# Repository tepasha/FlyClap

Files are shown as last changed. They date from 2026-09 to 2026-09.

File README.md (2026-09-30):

# 🪰 fly-defense

Модульні DIY-пристрої на Arduino та ESP32 для боротьби з мухами. Спершу збирається **основа** (плата, живлення, тумблер ARM, статус-LED), до неї роз'ємами JST-XH підключаються **модулі** на вибір: ІЧ-завіса, хлопавка, турель, сонар, камера. Три готові пристрої — типові комбінації модулів, див. [docs/modules.md](docs/modules.md).

| Проєкт | Принцип | Сенсор | Виконавчий механізм | Реакція |
|---|---|---|---|---|
| [**FlyClap**](docs/flyclap.md) | «Хлопавка»: муха пролітає між пластинами → вони схлопуються | ІЧ-завіса (4 промені) + LM339 | Соленоїд-засувка + пружини, серво взводить | ~25 мс |
| [**FlySonar — Arduino**](docs/flysonar.md) | Турель: ехолокатор сканує зону, водомет стріляє по цілі | HC-SR04 на pan-tilt | Помпа або клапан + сопло, 2 серви | ~3 с скан + ~1–2 с уточнення |
| [**FlySonar — ESP32**](docs/flysonar-esp32.md) | Та сама турель на одній ESP32-CAM: камера над підсвіченим фоном, бачить і мошку | ESP32-CAM + LED-панель | Клапан + розпилювач, 2 серви | ~70–90 мс |

## Структура

```
fly-defense/
├── platformio.ini              # проєкт PlatformIO (фреймворк Arduino): плати й середовища
├── lib/FlyDefense/             # бібліотека: основа (Base) і модулі
│   └── src/fly/                #   IrCurtain, ClapLatch, Turret, PanTilt, Nozzle, Sonar,
│                               #   CameraEyes, EyesLink, LinkOut
├── src/                        # прошивки = готові збірки модулів (по одній на середовище)
│   ├── flyclap/                # ІЧ-завіса + хлопавка
│   ├── flysonar/               # турель із сонаром (Arduino)
│   ├── flysonar_turret/        # турель на Arduino, цілі від ESP32 "очей"
│   ├── flysonar_eyes/          # ESP32-CAM як "очі" для Arduino
│   ├── flysonar_esp32/         # турель на одній ESP32-CAM
│   └── mybuild/                # шаблон своєї збірки
├── test/                       # тести модулів на ПК (pio test -e native), макет Arduino API
├── docs/
│   ├── modules.md              # основа + модулі, роз'єми JST-XH, свій модуль
│   ├── flyclap.md              # механіка, BOM, схема, налаштування
│   ├── flysonar.md             # Arduino-версія
│   ├── flysonar-esp32.md       # ESP32-версія: фон, підключення, калібрування
│   └── shopping-list.md        # зведений список покупок для обох проєктів
├── schematics/                 # схеми підключення, роз'єми JST-XH, ілюстрації (SVG + PNG)
├── cad/flyclap/                # корпус FlyClap для 3D-друку: STEP (FreeCAD), STL, модель CadQuery
├── cad/flysonar/               # турель FlySonar (обидві версії) і коробка основи для 3D-друку
├── tools/diagrams.py           # генератор схем
└── LICENSE
```

Що купити — див. [docs/shopping-list.md](docs/shopping-list.md). Для 3D-друку: корпус FlyClap — [cad/flyclap](cad/flyclap/README.md), турель FlySonar — [cad/flysonar](cad/flysonar/README.md).

## Як виглядають пристрої

| FlyClap | FlySonar — Arduino | FlySonar — ESP32 |
|---|---|---|
| FlyClap | FlySonar Arduino | FlySonar ESP32 |
| [схема підключення](schematics/flyclap-wiring.svg) · [варіант TSSP4038](schematics/flyclap-tssp.svg) | [схема підключення](schematics/flysonar-arduino-wiring.svg) | [схема підключення](schematics/flysonar-esp32-wiring.svg) |

Роз'єми основи й модулів — на окремій схемі: [modules-connectors](schematics/modules-connectors.svg).

Усі картинки — у папці [`schematics/`](schematics/) (SVG і PNG для друку/телефона). Їх генерує `tools/diagrams.py`: правите скрипт → `python3 tools/diagrams.py --png`.

## Збірка

Проєкт зроблено під [PlatformIO](https://platformio.org/) з фреймворком Arduino. Відкрийте теку репозиторію у VS Code з розширенням PlatformIO IDE або користуйтесь командним рядком; плати, тулчейни й бібліотеку `Servo` PlatformIO завантажить сам.

```bash
pio run -e flyclap -t upload
pio run -e flysonar -t upload
pio device monitor -b 115200
```

> Клони Uno на CH340 потребують драйвера CH340 (Windows/macOS), якщо плату не видно як COM/tty-порт.
>
> Прошивки використовують лише ресурси ATmega328P і працюють без змін і на Nano. Для нього є окремі середовища: `pio run -e flyclap_nano -t upload`, `pio run -e flysonar_nano -t upload`.

FlySonar, ESP32-версія: `pio run -e flysonar_esp32 -t upload` (ESP32-CAM) або `flysonar_esp32_s3` (ESP32-S3 CAM) — див. [docs/flysonar-esp32.md](docs/flysonar-esp32.md).

Інші варіанти: `flyclap_tssp` (завіса TSSP4038), `flysonar_turret` (+ `_nano`) разом з `flysonar_esp32_eyes` (ESP32 як «очі» для Arduino), `mybuild` (шаблон своєї збірки). Кожне середовище збирає одну прошивку з `src/`; модулі лежать у `lib/FlyDefense`.

### Тести
```bash
pio test -e native   # на ПК; потрібен g++ у PATH
```
Модулі бібліотеки на макеті Arduino API: основа (ARM, LED, конфлікти пінів), хлопавка, турель, збірка «турель + очі», симуляція сонара (віртуальна кімната + модель пелюстки HC-SR04), зір на синтетичних кадрах.

## Безпека

- **FlyClap**: механізм у корпусі з сіткою ~8 мм, пальці не пролазять. Соленоїд живиться лише короткими імпульсами.
- **FlySonar**: фільтр великих об'єктів не стріляє по руках і тваринах, а режим SAFE (тумблер ARM вимкнено) тільки логує цілі. Електроніку тримайте вище за рівень води й за перегородкою.
- Жодних лазерів і високої напруги: свідоме архітектурне рішення, пояснене в [docs/flyclap.md](docs/flyclap.md).

## Ліцензія

MIT, див. [LICENSE](LICENSE).

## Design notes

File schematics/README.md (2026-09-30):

# 📐 Схеми та ілюстрації

Схеми підключення й картинки «як виглядає пристрій» для всіх пристроїв. Кожна картинка є у двох форматах:

- **SVG** (у цій папці): масштабується без втрат, показується в документації на GitHub;
- **PNG** (у [`png/`](png/)): 2400 px завширшки, щоб відкрити на телефоні або роздрукувати.

| Пристрій | Як виглядає | Схема підключення |
|---|---|---|
| **FlyClap** | [SVG](flyclap-device.svg) · [PNG](png/flyclap-device.png) | варіант A (LM339): [SVG](flyclap-wiring.svg) · [PNG](png/flyclap-wiring.png)<br>варіант B (TSSP4038): [SVG](flyclap-tssp.svg) · [PNG](png/flyclap-tssp.png) |
| **FlySonar — Arduino** | [SVG](flysonar-arduino-device.svg) · [PNG](png/flysonar-arduino-device.png) | [SVG](flysonar-arduino-wiring.svg) · [PNG](png/flysonar-arduino-wiring.png) |
| **FlySonar — ESP32** | [SVG](flysonar-esp32-device.svg) · [PNG](png/flysonar-esp32-device.png) | [SVG](flysonar-esp32-wiring.svg) · [PNG](png/flysonar-esp32-wiring.png) |

| **Основа і модулі** | — | роз'єми JST-XH, розпіновка, що до якого піна: [SVG](modules-connectors.svg) · [PNG](png/modules-connectors.png) |

Кольори дротів на всіх схемах однакові: 🔴 +12 В · 🟠 +5 В · 🟣 живлення серв · 🔵 сигнали · ⚫ земля.

Зелені мітки біля сигналів — роз'єм основи й контакт: `B·3` означає роз'єм B, контакт 3. Типи роз'ємів описані в [docs/modules.md](../docs/modules.md#залізо-розєми-jst-xh).

Ілюстрації умовні (пропорції не в масштабі), це не креслення для кріплень. Подробиці — у документації: [FlyClap](../docs/flyclap.md), [FlySonar — Arduino](../docs/flysonar.md), [FlySonar — ESP32](../docs/flysonar-esp32.md).

## Як оновити

Картинки генерує [`tools/diagrams.py`](../tools/diagrams.py) (лише стандартна бібліотека Python). Змінили пін чи номінал — правите скрипт і з кореня репозиторію запускаєте:

```bash
python3 tools/diagrams.py          # лише SVG
python3 tools/diagrams.py --png    # SVG + PNG (потрібен Chromium; шлях можна задати змінною CHROME)
```

---

FlyClap — як виглядає
FlyClap — схема, варіант A
FlyClap — схема, варіант B
FlySonar Arduino — як виглядає
FlySonar Arduino — схема
FlySonar ESP32 — як виглядає
FlySonar ESP32 — схема
Основа і модулі — роз'єми JST-XH

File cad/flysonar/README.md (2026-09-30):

# FlySonar — турель pan-tilt для 3D-друку

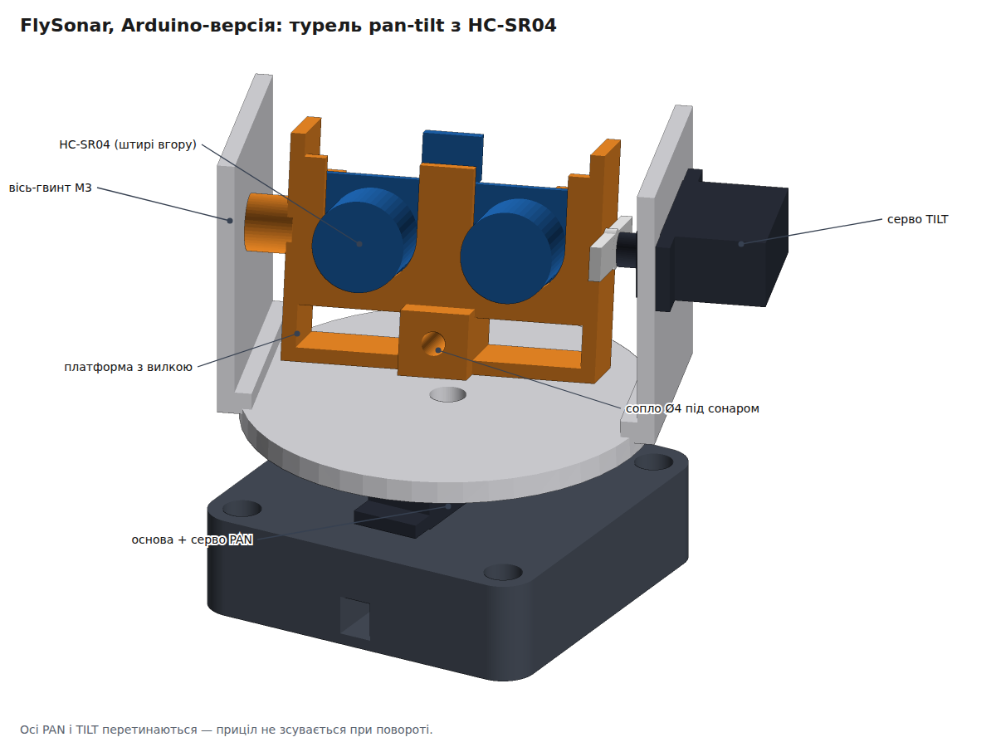
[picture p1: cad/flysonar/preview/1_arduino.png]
Arduino-версія


Одна поворотна основа під **дві версії** FlySonar:

| | Головка | Що ще друкувати |
|---|---|---|
| **Arduino-версія** ([docs/flysonar.md](../../docs/flysonar.md)) | `head_sonar`: HC-SR04 + сопло Ø4 під ним | — |
| **ESP32-версія** ([docs/flysonar-esp32.md](../../docs/flysonar-esp32.md)) | `head_nozzle`: лише сопло, точно на осі нахилу | `camera_post` + `camera_cradle` (кріплення ESP32-CAM) |

Під мікросерво **MG90S / SG90 / ES08MD**. Осі PAN і TILT перетинаються в одній точці, тож приціл не зсувається при повороті. Габарит турелі разом із серво TILT — близько 95 × 80 мм, висота до осі нахилу 65 мм.

| ESP32-версія | Нахил (розріз по центру) |
|---|---|
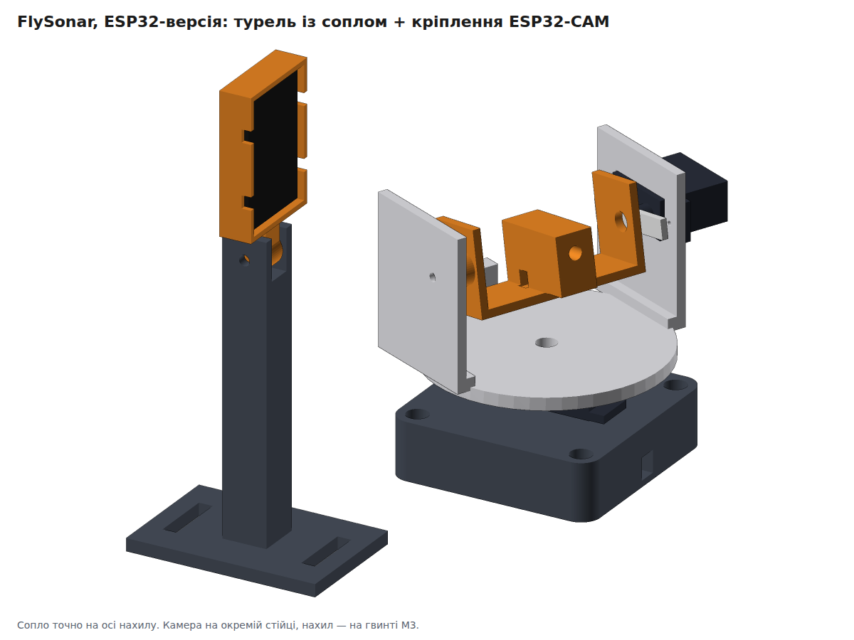
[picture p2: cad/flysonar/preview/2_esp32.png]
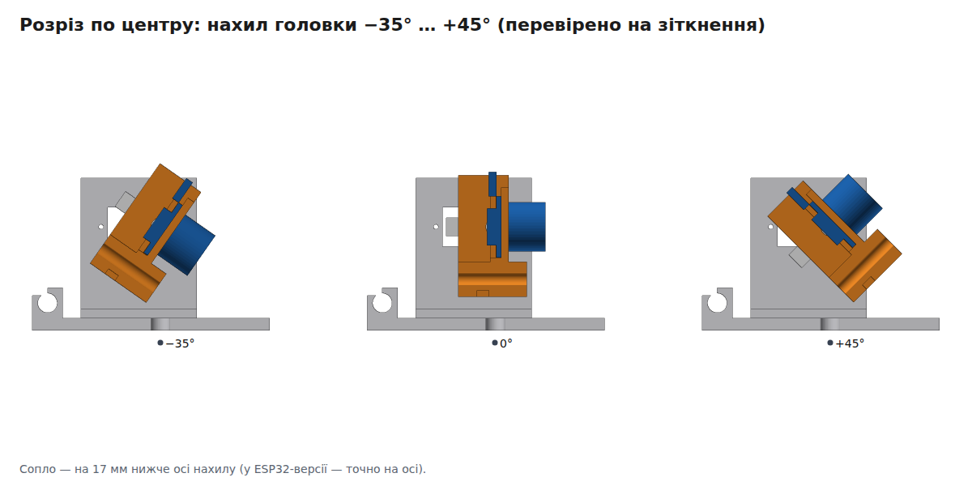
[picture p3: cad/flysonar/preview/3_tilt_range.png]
|  |  |

## Файли

| Що | Для чого |
|---|---|
| [`step/`](step/) | кожна деталь у STEP. **Відкривається у FreeCAD** (File → Open) |
| [`turret_arduino_assembly.step`](turret_arduino_assembly.step), [`turret_esp32_assembly.step`](turret_esp32_assembly.step) | складання з кольорами й назвами (разом із муляжами серв і HC-SR04) |
| [`stl/`](stl/) | для слайсера |
| [`flysonar_turret.py`](flysonar_turret.py) | параметрична модель (CadQuery) з перевірками |

Щоб отримати документ FreeCAD: відкрийте складання й зробіть **File → Save As → `.FCStd`**.

## Деталі для друку

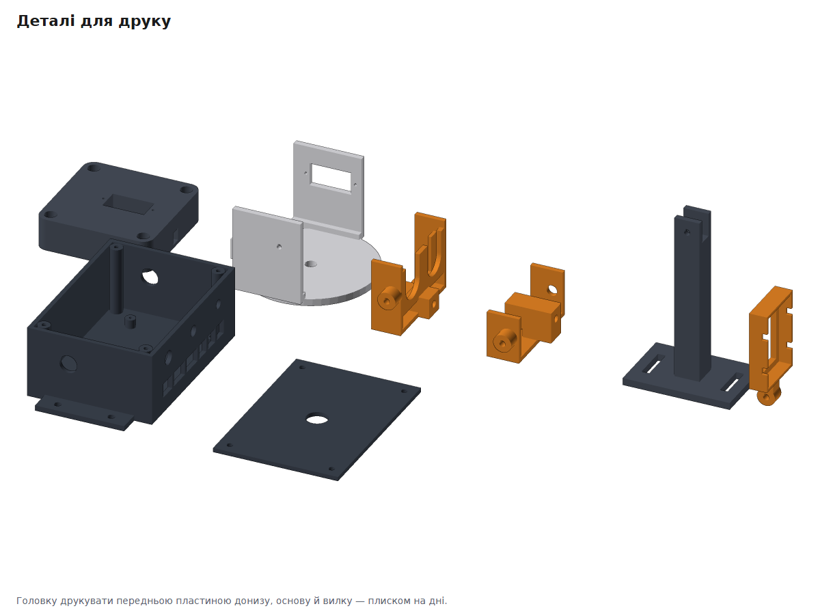
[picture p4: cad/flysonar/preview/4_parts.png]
Деталі


| Деталь | Орієнтація на столі | Примітка |
|---|---|---|
| `base` | плиском на дні | кишеня під серво PAN, проріз для кабелю, 4 отвори для кріплення до дошки |
| `yoke` | платформою донизу | платформа + вилка; права стійка з вікном під серво TILT, ззаду затискач шланга |
| `head_sonar` | передньою пластиною донизу | U-пази під випромінювачі HC-SR04, блок сопла |
| `head_nozzle` | плиском на дні | для ESP32-версії |
| `camera_post` | плиском на основі | стійка ESP32-CAM, висота осі 90 мм |
| `camera_cradle` | лицьовою рамкою донизу | рамка під плату 27 × 40,5 з великим вікном під лінзу |
| `electronics_box`, `electronics_lid` | коробка стоячи на дні, кришка плиском | коробка основи: плата 5 × 7 см, вікна під роз'єми JST-XH, лапки під шурупи |

PETG або PLA, шар 0,2 мм, 3 периметри, 20–30 %. Підтримки не потрібні.

## Кріплення та інше

| Що | К-сть | Для чого |
|---|---|---|
| Мікросерво MG90S (або цифрові ES08MD II) | 2 | PAN і TILT |
| Саморізи 2 мм з комплекту серв | 8 | вушка серв (по 4) |
| Саморізи з комплекту серв | 2 + 4 | центральні гвинти качалок + качалки до платформи й головки |
| Гвинт М3 × 12 | 1 | вісь нахилу з лівого боку: вкручується в стійку (отвір 2,8), головка обертається на ньому |
| Гвинти М3 / шурупи 3,5 мм | 4 | основа до дошки |
| Гвинт М3 × 16 + гайка | 1 | вісь нахилу камери (ESP32-версія) |
| Гвинти М4 | 2 | стійка камери до дошки |
| Латунна трубка / голка Ø4 | 1 | сопло |
| Стяжки 3 мм | 3 | сопло, плата ESP32-CAM |

## Складання

1. **Спершу виставте обидві серви на 90°** (прошивкою або тестером), і лише потім надягайте качалки. Тоді 90° означає «прямо вперед» і «горизонтально», як очікує прошивка.
2. **Серво PAN** вставте в основу (кабель у проріз, вушка лягають на верх), прикрутіть саморізами.
3. **Качалка PAN → платформа.** Покладіть качалку на низ платформи по центру, позначте отвори, просвердліть ∅1,5 і прикрутіть. Надягніть платформу на вал так, щоб вилка дивилась уперед (+X), і закрутіть центральний гвинт через отвір у платформі.
4. **Серво TILT** вставте у вікно правої стійки ззовні (вал усередину, корпус назад) і прикрутіть вушка.
5. **Головка.**
   - `head_sonar`: HC-SR04 **штирями вгору** опустіть згори в паз, щоб випромінювачі лягли в U-пази передньої пластини. Сопло вставте в отвір під сонаром і притягніть стяжкою.
   - `head_nozzle`: сопло в центральний отвір, стяжка.
6. **Качалка TILT → права щока головки.** Центр качалки над отвором ∅6, отвори просвердлити по місцю. Надягніть головку качалкою на вал серви (горизонтально), закрутіть центральний гвинт через отвір ∅6. Зліва вкрутіть М3 × 12 крізь стійку у втулку головки: головка обертається на гвинті.
7. **Шланг** з петлею-запасом проведіть через затискач ззаду платформи.
8. **ESP32-CAM:** плату вкладіть у рамку ззаду камерою до вікна, притягніть двома стяжками. Рамку вставте язичком у вилку стійки на М3 × 16: гайка дає фіксацію нахилу.

## Коробка основи й роз'єми модулів

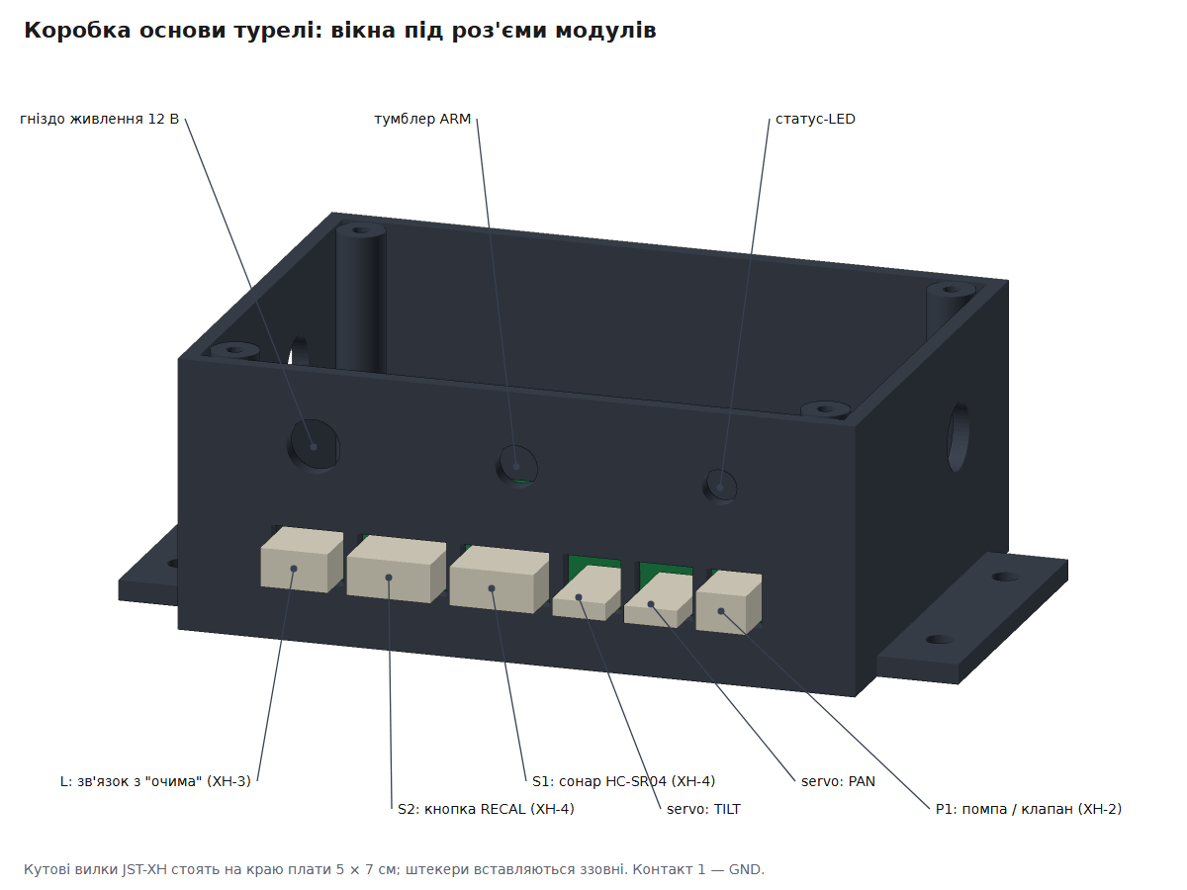
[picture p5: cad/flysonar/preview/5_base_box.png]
Коробка основи


`electronics_box` — це **основа** модульної системи ([docs/modules.md](../../docs/modules.md)): у ній контролер, DC-DC, силовий ключ, тумблер ARM і статус-LED, а модулі турелі підключаються роз'ємами. Коробка кріпиться до дошки чотирма шурупами через лапки. Плата 5 × 7 см стоїть на чотирьох стійках, зсунута до стінки з вікнами: між краєм плати й стінкою 0,6 мм. **Кутові вилки JST-XH (S2B/S3B/S4B/S6B-XH-A) і кутову гребінку серви припаюйте на самому краю плати, навпроти свого вікна**; тоді штекер модуля вставляється ззовні крізь стінку. Над вікнами — отвори під гніздо живлення ∅8, тумблер ARM ∅6,3 і статус-LED ∅5,2; у торцях — отвори ∅10 під силові дроти.

| Вікно | Роз'єм | Модуль | Версії |
|---|---|---|---|
| L | XH-3 | зв'язок з «очима» ESP32 | Arduino + «очі» |
| S2 | XH-4 | кнопка RECAL | Arduino (сонар) |
| S1 | XH-4 | сонар HC-SR04 | Arduino (сонар) |
| servo ×2 | 3-pin 2,54 | серви TILT і PAN | усі |
| P1 | XH-2 | помпа або клапан | усі |

В ESP32-версії контролер — сама ESP32-CAM на стійці камери; у коробці тоді лишаються DC-DC, ключ AO3400, тумблер ARM і роз'єми серв та клапана. Набір вікон задає список `BASE_PORTS` на початку скрипта; коробку будує `base_box()` у [`cad/cadlib.py`](../cadlib.py), спільна з корпусом FlyClap.

## Що перевіряє скрипт

`python3 cad/flysonar/flysonar_turret.py` (потрібно `pip install cadquery`):
- кожна деталь влазить на стіл 220 × 220 × 250 мм і є одним цілим тілом;
- **жодних зіткнень** на всьому діапазоні руху: нахил −35…+45°, поворот −90…+90° (прошивка використовує ±60°), для обох головок. Перевіряються вилка, серви, качалки, головка, HC-SR04 і основа;
- **HC-SR04 справді вставляється** згори в головку (плата ковзає 40 мм і ніде не чіпляє). Ця перевірка з'явилася після того, як перша версія з круглими отворами виявилася нескладальною;
- рамка камери нахиляється на ±25° і не зачіпає стійку;
- плата стає на стійки коробки основи, **кожен штекер проходить у своє вікно**, а сама коробка не заважає турелі й стійці камери.

Прапорці: `--no-export` (лише перевірки), `--preview` (картинки; numpy і Chromium, шлях можна задати в `CHROME`).

## Змінити розміри

Параметри на початку скрипта: розміри серви (`SV_*`), HC-SR04 (`SR_*`), діаметр сопла `NOZ_D` (6,2 для силіконової трубки 4 × 6), висота осі нахилу, висота стійки камери, зазор `CLR`. Після змін запустіть скрипт: перевірки покажуть, чи нічого не зачіпається.

## Обмеження (чесно)

- **Розміри серв і HC-SR04** взято з типових креслень, а клони відрізняються до 1 мм. **Звірте штангенциркулем** і за потреби виправте `SV_*` / `SR_*`. Найважливіші — відстань від торця корпусу до вала `SV_SHAFT_OFF` і висота вушок `SV_TAB_Z`.
- **Вікна під роз'єми** розраховано за розмірами колодок JST-XH з даташита (ширина 2,5 × (n − 1) + 4,9 мм) із зазором 0,8 мм. Розташування вилок на платі залежить від вашого монтажу: приміряйте плату в коробці до пайки.
- **Отвори під гвинти качалок** не змодельовані, бо форма качалок різна. Їх свердлять по місцю (крок 3 і 6).
- **Не надруковано й не перевірено на залізі:** перевірки геометричні. Мікросерво тримає головку з HC-SR04 без проблем, але шланг має бути м'який, з петлею, щоб не тягнув турель.
- **Паралакс сопла.** У Arduino-версії сопло на 17 мм нижче сонара, і прошивка це враховує (`TILT_NOZZLE_OFFSET10`). Після складання уточніть поправки пробними пострілами, як описано в [docs/flysonar.md](../../docs/flysonar.md).

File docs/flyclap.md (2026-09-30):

# FlyClap — збивач мух на льоту на Arduino

## Чому саме така архітектура

| Ідея | Чому ні |
|---|---|
| Камера + наведення | ATmega328 не потягне комп'ютерний зір; муха летить 1–3 м/с, pan-tilt просто не встигне |
| Лазер | Небезпечно для очей людей і тварин, не варто навіть як експеримент |
| Електросітка | Потрібна висока напруга — не для DIY-плати на столі |

**Рішення:** не наводимося на муху, а робимо зону, де вона гарантовано пролетить (приманка), і перекриваємо її всю одним швидким механізмом. Arduino тут робить те, що вміє найкраще — реагує за мікросекунди.

Бюджет часу: переривання ~5 мкс → засувка ~5 мс → пластини схлопуються ~15–20 мс. За ~25 мс муха пролітає 3–6 см, тому пластини 15×15 см з ІЧ-завісою по центру її накривають.

## Механіка

FlyClap — як виглядає пристрій

> **Корпус для 3D-друку** (STEP для FreeCAD, STL, інструкція зі складання): [cad/flyclap](../cad/flyclap/README.md).

- Дві легкі пластини (оргскло 2 мм або PET), на петлях, стягуються пружинами/гумками.
- Засувка тримає їх розведеними, соленоїд її вибиває.
- Сервопривід розводить пластини назад до зачеплення засувки, кінцевик підтверджує "взведено", важіль відходить.
- Корпус закритий сіткою з вічком ~8 мм — механізм не може прищемити пальці.

## Компоненти (BOM)

### Контролер і живлення
| Деталь | К-сть | Примітка |
|---|---|---|
| Arduino **Nano** (ATmega328P, CH340) | 1 | Рекомендовано: дешевше й компактніше за Uno + Proto Shield. Uno R3 теж підходить |
| Макетна плата 5×7 см (для Nano) або Proto Shield (для Uno) | 1 | Компаратор, MOSFET і роз'єми розпаюються на ній |
| БЖ 12 В 2 А + гніздо DC 5.5×2.1 | 1 | |
| DC-DC понижувач на 5–6 В, ≥3 А (XL4015 / LM2596) | 1 | Тільки для серви |
| Електроліт 470–1000 мкФ 16 В | 1 | Біля серви |
| Електроліт 1000–2200 мкФ 25 В | 1 | Біля соленоїда, див. «Швидкий соленоїд» |
| Кераміка 100 нФ | 5 | Біля LM339, Arduino, DC-DC |

### ІЧ-завіса (базовий варіант, `IrCurtain::COMPARATOR`)
| Деталь | К-сть | Примітка |
|---|---|---|
| ІЧ-світлодіод 940 нм (напр. TSAL6200) | 4 (+2 запас) | |
| Резистор 150 Ом | 4 | Струм світлодіодів ~25 мА від 5 В |
| Фототранзистор з ІЧ-фільтром (TEFT4300) | 4 (+2) | |
| Резистор 10 кОм | 8 | 4× підтяжка фототранзисторів, 4× підтяжка виходів LM339 (відкритий колектор, без них не працює) |
| **Резистор 1 МОм** | 4 | Гістерезис компаратора, див. нижче |
| LM339 + панелька DIP-14 | 1 | |
| Підстроювальний резистор 10 кОм (багатообертовий 3296) | 4 | Дільник 5 В ↔ GND, повзунок → вхід «−» |

### Виконавчі механізми та керування
| Деталь | К-сть | Примітка |
|---|---|---|
| Соленоїд 12 В push/pull, хід ~5 мм (типу JF-0530B) | 1 | |
| IRLZ44N | 1 | + 100 Ом у затвор, 10 кОм затвор→GND |
| Діод 1N5819 | 1 | Паралельно котушці |
| Сервопривід MG996R | 1 | Живлення від DC-DC, **не** від піна 5V |
| Мікроперемикач (кінцевик) з важелем | 1 | |
| **Пасивний** п'єзо-бузер | 1 | `tone()` потребує пасивного; у TSSP-варіанті — активний |
| Тумблер ARM, світлодіод + 330 Ом | 1 | |

### Механіка
- Оргскло 2 мм / PET — 2 пластини 15×15 см, 2–4 маленькі петлі, пружини розтягу або гумки
- Засувка (3D-друк або алюмінієвий кутик), корпус, сітка з вічком ~8 мм
- Чорна термоусадка на фототранзистори, дроти, клемники, приманка

**Живлення Uno:** 12 В від того ж БЖ можна подати в DC-джек або на Vin, вбудований стабілізатор Uno це приймає. Але 5V-пін Uno дає лише ~500 мА, і соленоїд та серва від нього **не** живляться.

## Схема підключення

FlyClap — схема підключення, варіант A

| Arduino | Куди |
|---|---|
| D4–D7 | виходи LM339 (підтяжка 10 кОм до 5 В). Промінь цілий = LOW, перекритий = HIGH |
| D8 | кінцевик на GND (LOW = взведено) |
| D9 | затвор IRLZ44N → соленоїд до +12 В |
| D10 | сигнал серви |
| D11 | бузер |
| D13 | статус-LED |
| A0 | тумблер ARM на GND |

Кожен канал завіси: фототранзистор + резистор 10 кОм → вхід "+" компаратора; підстроювальник → вхід "−". Колектор фототранзистора закрити трубкою (термоусадка) від зовнішнього світла.

**Гістерезис (обов'язково).** Резистор **1 МОм з виходу кожного компаратора на його вхід «+»**. Фототранзистор дає повільний фронт, і без гістерезису компаратор на порозі «дзвенить»: десятки перемикань, кожне з яких викликає переривання. Гістерезис ≈ 5 В × 10 кОм / 1 МОм ≈ 50 мВ. Якщо на межі все одно тремтить, поставте 470 кОм (~100 мВ).

**Швидкий соленоїд.** Електроліт 1000–2200 мкФ між +12 В і силовою землею якомога ближче до соленоїда. Він віддає пусковий струм, тому засувка вибивається швидше, а БЖ і Arduino не просідають у момент пострілу.

### Альтернатива: модульована завіса TSSP4038 (`IrCurtain::TSSP`, середовище `flyclap_tssp`)

Замість фототранзисторів, LM339 і підстроювальників ставляться 4 приймачі **TSSP4038**, які реагують лише на ІЧ, модульоване на 38 кГц. Завіса перестає боятися сонця й ламп, і налаштовувати нічого не треба. Прошивка генерує несучу апаратно (Timer2 → D3).

FlyClap — варіант B, TSSP4038

| Що | Підключення |
|---|---|
| TSSP4038 ×4 | OUT → D4–D7, VS → 5 В через 100 Ом + 100 нФ до GND (на кожен приймач) |
| ІЧ-світлодіоди ×4 | кожен через свій резистор 68 Ом від 5 В на колектор BC337 (або стік IRLZ44N) |
| D3 | 1 кОм → база BC337, емітер → GND |
| D11 | **активний** бузер (Timer2 зайнятий несучою, `tone()` недоступний) |

У цьому варіанті всі приймачі бачать усі світлодіоди, тому **трубки на світлодіодах і на приймачах обов'язкові**. Інакше перекритий промінь «підсвітять» сусіди. Якщо промінь не перекривається сірником, збільшуйте резистор світлодіодів (68 → 220 Ом → 1 кОм): на 15 см сигналу вистачає з великим запасом. Реакція приймача ~0.3–0.5 мс, у бюджеті 25 мс це непомітно.

Найпростіший варіант без компаратора: готові модулі ІЧ-завіси (break-beam) з виходом на відкритому колекторі підключаються прямо в D4–D7 у режимі `COMPARATOR` з підтяжками 10 кОм.
**Загальна земля обов'язкова**, силові земля соленоїда/серви — зіркою до БЖ, не через Uno.

## Налаштування

1. Прошити, відкрити Serial Monitor на 115200.
2. Тумблер ARM вимкнено. Для кожного каналу крутити підстроювальник, поки вихід стабільно LOW при чистому промені і HIGH, коли його перекриває сірник.
3. Підібрати `SERVO_COCK_DEG`, щоб засувка чітко клацала, і `SERVO_REST_DEG`, щоб важіль не заважав пластинам (константи в `lib/FlyDefense/src/fly/ClapLatch.h`).
4. Увімкнути ARM: пік → взвод → короткий пік = "ARMED".

## Індикація

| LED | Значення |
|---|---|
| коротке мигання раз на 2 с | SAFE: ARM вимкнено |
| горить | ARM, усе готово |
| повільно блимає | ARM, модуль зайнятий |
| швидко блимає | аварія, помилка конфігурації або немає зв'язку |

Та сама мова LED у всіх пристроях, див. [modules.md](modules.md#основа-flybase).

У FlyClap «зайнятий» — це взвод або очікування чистої завіси. Швидке блимання з довгим гудком — FAULT (застрягла засувка або щось лежить у промені). Скидання: вимкнути й увімкнути ARM.

## Прошивка — ключові рішення

Прошивка — `src/flyclap/main.cpp`: основа + модулі `IrCurtain` (тригер) і `ClapLatch` (виконавець) з бібліотеки `lib/FlyDefense`. Будь-який з них можна замінити, див. [modules.md](modules.md). Модулі підключаються до основи роз'ємами JST-XH (зелені мітки на схемі); вікна під них є в блоці електроніки корпусу.

- Соленоїд вмикається **прямо в ISR** (pin-change переривання завіси), не в `loop()` — економить до кількох мс.
- Повторне читання через 30 мкс у ISR відсіює ЕМ-завади від самого соленоїда та серви.
- Озброєння лише після 500 мс стабільно чистої завіси, щоб не стріляти по прилиплій мусі.
- Лічильник **спрацювань** (`claps`) зберігається в EEPROM. Це кількість схлопувань, а не підтверджених мух: пил чи комаха теж рахуються.
- Серво під'єднується (`attach`) лише на час руху. Коли важіль повернувся в спокій, воно відключається: не тремтить, не гуде, не тягне струм і не наводить завад на завісу. Важіль у спокої ніщо не навантажує, тож утримувати його не треба.
- Час пострілу, записаний в ISR (32 біти), `tick()` модуля читає в `ATOMIC_BLOCK`.

## Ідеї для v2

- Два шари завіси → оцінка швидкості та затримка спрацювання під траєкторію.
- OLED із лічильником, живлення від 18650.

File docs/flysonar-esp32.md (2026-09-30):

# FlySonar — ESP32-версія (камера, бачить мошку)

Одна плата **ESP32-CAM** або **ESP32-S3-CAM** робить усе: бачить комаху на підсвіченому фоні, веде ціль, наводить серви й відкриває клапан. **Arduino не потрібен.** Вона бачить **мошку 1–3 мм** і може стріляти по цілі в польоті.

Arduino-версія (сонар HC-SR04) описана в [flysonar.md](flysonar.md).

| | Arduino-версія | ESP32-версія |
|---|---|---|
| Плата | Arduino Uno / Nano | ESP32-CAM або ESP32-S3-CAM |
| Сенсор | HC-SR04 на турелі | камера над підсвіченим фоном |
| Кого бачить | мухи 6–8 мм, що сидять, 10–40 см | мухи й мошка 1–3 мм, у т.ч. в польоті |
| Точність | ~0,5° після уточнення | ~1 мм у площині фону (після калібрування) |
| Реакція | ~3 с скан + 1–2 с уточнення | ~70–90 мс |
| Прошивка | `src/flysonar` | `src/flysonar_esp32` |

FlySonar, ESP32-версія — як виглядає пристрій

> **Турель і кріплення камери для 3D-друку:** [cad/flysonar](../cad/flysonar/README.md) (головка `head_nozzle` + `camera_post` / `camera_cradle`).

## Чому саме так

- **Підсвічений фон.** Комаха на світлій панелі дає чорну тінь з величезним контрастом, без складного розпізнавання. Так працюють і промислові оптичні «паркани» для комарів. Світла панель ще й сама приваблює комах, і вони **сідають на неї**. Це найлегші цілі, і для них немає паралакса (див. нижче).
- **Роздільність.** QVGA 320×240 на полі шириною ~30 см дає ~1 мм на піксель, тобто мошка займає 2–4 пікселі. Алгоритм ловить плями від 2 пікселів.
- **Камера нерухома, окремо від турелі.** Калібрування «піксель → кути серв» робиться тестовими пострілами, тож зміщення сопла й провисання струменя входять у модель автоматично.
- **Два ядра.** Зір працює в `loop()`. Серви, клапан, тумблер ARM і світлодіод обслуговує окрема задача кожну 1 мс, тому тривалість пострілу точна (±1 мс) і не залежить від кадрів камери.

## Що купити

| Деталь | К-сть | Примітка |
|---|---|---|
| ESP32-CAM AI-Thinker (OV2640, 4 МБ PSRAM) | 1 | Найдешевша. Або Freenove ESP32-S3-WROOM CAM (USB вбудований, більше вільних пінів) |
| Програматор ESP32-CAM-MB (USB) | 1 | Лише для AI-Thinker |
| LED-планшет для копіювання A4 (USB 5 В) | 1 | Фон. A3 теж можна, але тоді ~1,3 мм/піксель |
| Прозора плівка або оргскло 2 мм на панель | 1 | Захист від бризок, протирається |
| Кронштейн для камери | 1 | Жорсткий: камера не повинна зсуватися після калібрування |
| 2× цифрові мікросерво (напр. EMAX ES08MD II) або MG90S | 2 | Цифрові точніші (мертва зона ≤2–3 мкс проти ~1° у MG90S) |
| Pan-tilt кронштейн під мікросерво | 1 | |
| Садовий обприскувач 1,5–2 л + клапан 12 В NC **прямої дії** + фітинги | 1 | Або помпа R385 (`SHOOTER_VALVE 0`) |
| Латунне сопло-розпилювач 0,3–0,5 мм | 1–2 | Конус 2–4 см прощає залишкову похибку |
| MOSFET для 3,3 В логіки: AO3400 / IRLML6344 (SOT-23) або модуль-ключ «3.3V logic» | 1 | IRLZ44N від 3,3 В відкривається не повністю |
| Діод 1N5819, резистори 100 Ом і 10 кОм | 1 | Діод паралельно клапану, 100 Ом у затвор, 10 кОм затвор→GND |
| БЖ 12 В 2 А | 1 | Клапан |
| DC-DC 5 В **≥3 А** + електроліт 1000 мкФ | 1 | ESP32 і серви. ESP32-CAM дуже чутлива до просадок живлення |
| Тумблер ARM, чорна наліпка ∅3–5 мм (маркер для калібрування) | 1 | |

## Підключення (самостійна роль)

FlySonar, ESP32-версія — схема підключення

| Сигнал | ESP32-CAM AI-Thinker | Freenove ESP32-S3 CAM |
|---|---|---|
| Серво PAN | GPIO14 | GPIO1 |
| Серво TILT | GPIO15 | GPIO14 |
| Затвор MOSFET клапана | GPIO13 | GPIO21 |
| Тумблер ARM → GND | GPIO12 | GPIO47 |
| Статус-LED | GPIO33 (вбудований) | GPIO2 (вбудований) |

- **GPIO12 на AI-Thinker — strapping-пін:** якщо на старті він HIGH, плата не завантажиться. Тумблер ARM підключайте **лише на GND і без зовнішньої підтяжки**, підтяжку прошивка вмикає сама вже після старту.
- На AI-Thinker GPIO13/14/15 — лінії SD-картки, картку не вставляйте.
- Для інших S3-плат перевірте, що піни вільні: вони задаються константами `PIN_*` на початку скетча. Якщо пін зайнятий камерою чи іншим модулем, у Serial буде `CONFIG ERROR`.
- **Живлення.** Серви живляться від DC-DC 5 В, ESP32 — від того ж DC-DC (пін 5V), з електролітом 1000 мкФ біля серв. Земля спільна з БЖ 12 В. Від'єднаний сигнал серви не повинен «висіти»: спершу підключайте землю.
- ⚠️ **Вода та електроніка.** Плату й живлення розміщуйте вище рівня бака і за перегородкою.

| LED | Значення |
|---|---|
| коротке мигання раз на 2 с | SAFE: ARM вимкнено |
| горить | ARM, усе готово |
| повільно блимає | ARM, модуль зайнятий |
| швидко блимає | аварія, помилка конфігурації або немає зв'язку |

Та сама мова LED у всіх пристроях, див. [modules.md](modules.md#основа-flybase).

## Прошивка

| Плата | PlatformIO |
|---|---|
| ESP32-CAM AI-Thinker | `pio run -e flysonar_esp32 -t upload` |
| Freenove ESP32-S3 CAM / ESP32-S3-EYE | `pio run -e flysonar_esp32_s3 -t upload` |

Прошивка — `src/flysonar_esp32/main.cpp`. Піни камери й турелі вона обирає сама за типом чипа (ESP32 → AI-Thinker, ESP32-S3 → Freenove / S3-EYE). На її початку — `SHOOTER_VALVE`: 1 — клапан (50 мс), 0 — помпа (120 мс).

Збірка: основа + модулі `Turret` і `CameraEyes`, див. [modules.md](modules.md).

> Обидві плати й обидві ролі збираються в PlatformIO (arduino-esp32 2.0.17). Логіку зору й турелі протестовано на ПК (`pio test -e native`), але на реальному залізі ця версія ще не перевірялась.

### Роль «очі» для Arduino (опційно)

Якщо Arduino-турель уже зібрана, ESP32 може працювати лише як камера й передавати кути на Arduino по UART. Стріляє тоді Arduino.
- ESP32: прошивка `src/flysonar_eyes` (`pio run -e flysonar_esp32_eyes -t upload` або `_s3_eyes`): модулі `CameraEyes` + `LinkOut`.
- Arduino: прошивка `src/flysonar_turret` (`pio run -e flysonar_turret -t upload`): модулі `Turret` + `EyesLink`.
- Підключення: GPIO14 ESP32 → D0 (RX) Arduino, GND → GND. На час прошивки Arduino від'єднуйте D0 і нічого не надсилайте з монітора порту Arduino.

## Калібрування

Монітор порту **ESP32** на 115200. Команди — одна клавіша:

| Клавіша | Дія |
|---|---|
| `m` | увімкнути/вимкнути режим калібрування |
| `a d w s` | довернути турель на 0,5° (великі `A D W S` — на 5°) |
| `f` | тестовий постріл 40 мс (тумблер ARM має бути увімкнений) |
| `c` | записати точку: пляма маркера ↔ поточні кути |
| `u` | скасувати останню точку |
| `v` | розрахувати й зберегти (≥3 точки) |
| `b` | перевчити фон |
| `t` | стріляти також по цілях у польоті (з упередженням) |
| `p` | стан: fps, калібрування, ціль, швидкість |

Порядок:
1. Увімкнути панель, прибрати все з поля. Через 2,5 с після старту експозиція фіксується і фон вивчається сам (або натисніть `b`).
2. `m`. Кнопками `a d w s` навести турель приблизно в кут поля.
3. `f`: на плівці з'явиться мокра пляма. Покладіть маркер точно на неї, тоді `c` (у кадрі має бути рівно одна темна точка).
4. Повторити для 4–6 точок по всьому полю: кути й центр. Точки не мають лежати на одній прямій.
5. `v`. Плата покаже найгіршу залишкову похибку в градусах. Приберіть маркер, протріть плівку, натисніть `b`, потім `m` (вихід у бойовий режим).

Калібрування зберігається у флеш-пам'яті й переживає перезавантаження.

## Як працює

1. **Фон** — ковзне середнє кадрів. Під темними плямами фон не оновлюється, тому муха, що сіла, не «розчиняється» у фоні.
2. **Маска.** Піксель вважається темною плямою, якщо він на панелі (фон ≥ `backdropMin`) і темніший за фон на `darkDelta`.
3. **Плями.** Зв'язні області від 2 пікселів і не більші за 14×14 — цілі. Більші, або понад 400 темних пікселів у кадрі (рука, кіт, людина), блокують стрільбу на 3 с і миттєво закривають клапан.
4. **Трекер альфа-бета** згладжує позицію й оцінює швидкість у пікселях/с.
5. **Приціл.** Ціль повільніша за 15 пікс/с вважається нерухомою, і приціл береться в поточну точку. По цілі в польоті приціл береться в точку, де вона буде через `latencyMs` (70 мс), але лише з увімкненим `t`.
6. **Дозвіл стріляти** дає зір: ціль підтверджена ≥5 кадрів поспіль, у поточному кадрі видна, великого об'єкта не було 3 с.
7. **Турель** (модуль `Turret`, та сама логіка, що й в Arduino-версії) стріляє лише коли ARM увімкнено, серво доїхало, дозвіл свіжий (≤150 мс), серія не вичерпана (3 постріли) і минув кулдаун. Вимкнення ARM закриває клапан посеред пострілу.
8. **Серви** керуються через драйвер LEDC на окремому таймері (не на таймері тактування камери) з кроком ~0,12°.

## Обмеження (чесно)

- **Паралакс.** Камера бачить 2D. Калібрування зроблене в площині панелі, тож ціль на відстані Δ перед панеллю дає похибку ≈ (відстань камера↔сопло) × Δ / (відстань до панелі). Ставте камеру якомога ближче до осі турелі (3–5 см). Найточніше влучання — по комахах, що сіли на панель, тож біля неї варто покласти приманку (сироп, оцет).
- **Політ.** OV2640 дає ~25–30 кадрів/с, повна затримка ~70–90 мс. Мошка за цей час зміщується на 3–8 см, і упередження компенсує це лише для рівного польоту. Для цілей у польоті використовуйте розпилювач, а не голку.
- **Змазування.** OV2640 має «біжучий» затвор, тож швидка комаха виходить злегка розмазаною. На центроїд це майже не впливає.
- **Освітлення.** Фон має бути **стабільно** яскравим. Пряме сонце на панель чи миготливі лампи дають хибні плями. Експозиція фіксується після старту: якщо світло в кімнаті змінилося, перезавантажте плату або натисніть `b`.
- **Живлення ESP32-CAM.** Найчастіша проблема — перезавантаження, коли рушають серви. Окремий DC-DC ≥3 А і електроліт біля серв обов'язкові.

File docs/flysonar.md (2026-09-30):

# FlySonar — Arduino-версія (сонар HC-SR04)

FlySonar існує у двох версіях:

| | **Arduino-версія** (цей документ) | [**ESP32-версія**](flysonar-esp32.md) |
|---|---|---|
| Плата | Arduino Uno / Nano | ESP32-CAM або ESP32-S3-CAM, без Arduino |
| Сенсор | HC-SR04 на турелі | камера над підсвіченим фоном |
| Кого бачить | мухи 6–8 мм, що сидять, 10–40 см | мухи й мошка 1–3 мм, у т.ч. в польоті |
| Точність | ~0,5° після уточнення | ~1 мм у площині фону |
| Прошивка | `src/flysonar` | `src/flysonar_esp32` |

Arduino-версію можна також поєднати з ESP32 у ролі «очей» (прошивки `src/flysonar_turret` + `src/flysonar_eyes`): камера шукає ціль, а Arduino стріляє (див. [flysonar-esp32.md](flysonar-esp32.md#роль-очі-для-arduino-опційно)).

Два види «ствола» (`SHOOTER_VALVE`): помпа R385 або клапан + бак під тиском.

## Чесна інженерна оцінка

**Сонар.** HC-SR04 працює на 40 кГц (довжина хвилі ≈ 8,6 мм), а муха має розмір 6–8 мм. Ехо від неї слабке. Реалістична дальність виявлення **10–40 см**, і тільки в тихому акустичному середовищі. Від мошки 2 мм ехо ще в ~1800 разів (−33 дБ) слабше, бо сила відбиття від об'єкта, меншого за хвилю, падає як розмір⁶. **Мошку сонар не бачить принципово.** Пелюстка ~15°, тому по сітці кут відомий лише з точністю ±5°. Прошивка уточнює його дрібним сканом до ~0,5°, але це займає ~1–2 с, тож стріляємо лише по мусі, що сидить.

**Камера.** Комаха на яскравому фоні дає контрастну тінь навіть розміром у 2–3 пікселі, тому оптика бачить і мошку. Див. [ESP32-версію](flysonar-esp32.md).

## Як працює режим сонара

1. **Калібрування фону.** Турель обходить усі кути й запам'ятовує, де стіни та меблі.
2. **Скан змійкою.** Сітка 25×3 з кроком 5°. Шукає ехо, яке ближче за фон мінімум на 10 см і лежить у межах 8–60 см.
3. **Підтвердження.** Медіана з 3 вимірів.
4. **Фільтр великих об'єктів.** Рахуємо суцільну смугу клітинок з тією самою відстанню в обидва боки. Пелюстка ~16° накриває до 4 клітинок навіть для точкової мухи, тому 5+ клітинок поспіль означає руку чи кота, і турель **не стріляє**.
5. **Уточнення центроїдом.** Дрібний скан ±10° кроком 2° по горизонталі, потім по вертикалі. Напрям на ціль береться як середнє кутів, де є ехо (пелюстка симетрична). Якщо ехо є на краю вікна, вікно зсувається й скан повторюється (до 3 разів).
6. **«Сидить чи летить».** 4 виміри в точці центроїду. Розкид ≤2 см означає, що муха сидить. `STATIC_ONLY = 1` (за замовчуванням) дозволяє стріляти лише по нерухомій цілі: по мусі в польоті сонар за 1–2 с не влучить.
7. **Постріл.** Корекція на зміщення сопла і падіння струменя, імпульс помпи чи клапана. Після перевірки ще до 3 пострілів, потім кулдаун.

У симуляції (`pio test -e native`) найгірша похибка прицілу по нерухомій цілі в 8 положеннях становить ≤0,5°, а при наведенні по вузлах сітки вона сягала 2–7°.

## Механіка

FlySonar, Arduino-версія — як виглядає пристрій

> **Турель для 3D-друку** (обидві версії; STEP для FreeCAD, STL, інструкція): [cad/flysonar](../cad/flysonar/README.md).

- Сопло кріпиться паралельно осі сонара. Залишкову різницю компенсують `PAN/TILT_NOZZLE_OFFSET10` (у десятих градуса).
- Шланг 4 мм, м'який силікон, з запасом петлі, щоб не тягнув серви.
- Зворотний клапан біля сопла: струмінь стартує миттєво, а не після заповнення трубки.
- **Сопло-розпилювач** дає конус ~2–4 см на 30 см. Це перекриває залишкову похибку, а для мошки навіть дрібний туман уже смертельний.

### Серви: точність

Прошивка керує сервами через `writeMicroseconds` з роздільністю 0,1°. Реальна точність упирається в **мертву зону** серви: у MG90S це ~1°. Для режиму камери краще взяти **цифрові мікросерво з металевими шестернями й мертвою зоною ≤2–3 мкс** (напр. EMAX ES08MD II; дивіться характеристики конкретної моделі). Вони тримають ~0,2–0,3°.

### Ствол: помпа чи клапан (`SHOOTER_VALVE`)

| | Помпа R385 (`0`) | Клапан + бак під тиском (`1`) |
|---|---|---|
| Затримка до струменя | 50–100 мс, поки помпа набирає тиск | 5–10 мс |
| Тиск / швидкість | ~0,3–0,5 бар, повільний струмінь | 1,5–3 бар, ~15–20 м/с (30 см за ~15–20 мс) |
| Провисання струменя | помітне (0,25°/см, `Nozzle::PUMP`) | мале (0,08°/см, `Nozzle::VALVE`) |
| Імпульс | 120 мс | 50 мс |

**Варіант з клапаном:** садовий обприскувач 1,5–2 л (накачується ручним насосом) → шланг → **нормально закритий клапан прямої дії 12 В** → сопло. Беріть саме клапан прямої дії: пілотні клапани (з мембраною) не відкриваються при малому тиску. Клапан підключається на те саме місце, що й помпа (D5 → IRLZ44N), паралельно котушці ставиться діод 1N5819.

## Компоненти (режим сонара)

- Arduino Uno R3 або Nano
- HC-SR04 (краще JSN-SR04T **не брати**: у нього мертва зона 20 см)
- 2× MG90S (металеві шестерні) + pan-tilt кронштейн, або цифрові мікросерво (див. вище)
- Помпа 12 В діафрагмова (напр. R385) або 5 В мембранна, **або** клапан + обприскувач; IRLZ44N; діод 1N5819; 100 Ом у затвор, 10 кОм затвор→GND
- Зворотний клапан 4 мм, силіконова трубка, резервуар
- БЖ 12 В 2 А + DC-DC на 5–6 В ≥2 А для серв, електроліт 470–1000 мкФ біля серв, 100 нФ біля HC-SR04
- Кнопка перекалібрування, тумблер ARM, LED + 330 Ом

Для ESP32-версії див. [flysonar-esp32.md](flysonar-esp32.md). Повний список покупок: [shopping-list.md](shopping-list.md).

## Підключення

FlySonar, Arduino-версія — схема підключення

| Arduino | Куди |
|---|---|
| D0 (RX) | *(лише режим камери)* TX ESP32 (GPIO14). Від'єднувати на час прошивки Arduino |
| D2 | TRIG HC-SR04 |
| D3 | ECHO HC-SR04 |
| D4 | кнопка RECAL → GND |
| D5 | затвор MOSFET помпи або клапана |
| D9 | сигнал PAN серви |
| D10 | сигнал TILT серви |
| D13 | LED |
| A0 | тумблер ARM → GND |

⚠️ **Вода та електроніка.** Плату й БЖ розміщуйте вище рівня резервуара і за перегородкою. Помпу не ганяйте насухо. Серви живіть від окремого DC-DC, з конденсатором 470 мкФ; вони дають просадки, від яких Uno ребутиться. Земля спільна. Сам Uno можна живити 12 В через DC-джек, але серви й помпу від його 5V-піна не живити.

## Збірка

| Середовище PlatformIO | Що |
|---|---|
| `flysonar` / `flysonar_nano` | `src/flysonar`: сонар |
| `flysonar_turret` / `flysonar_turret_nano` | `src/flysonar_turret`: цілі від ESP32 у ролі «очі» (Arduino-частина) |

На початку `src/flysonar/main.cpp` задаються `SHOOTER_VALVE` (помпа чи клапан) і `STATIC_ONLY`. Збірка складається з модулів `Turret` (голова pan-tilt + ствол) і `Sonar`, див. [modules.md](modules.md). Модулі підключаються до основи роз'ємами JST-XH (зелені мітки на схемі); коробка основи з вікнами під них — у [cad/flysonar](../cad/flysonar/README.md).

## Налаштування (режим сонара)

1. Прибрати все із зони, увімкнути. Турель сама відкалібрується (у Serial: `Calibrating background...` → `Background ready`).
2. Тумблер ARM вимкнено = режим SAFE: ціль пишеться в Serial (115200) з уточненими кутами й позначкою still/moving, але постріл не відбувається. Помахати сірником на нитці на 20–30 см і подивитись, чи ловиться.
3. Тонко налаштувати `DELTA_CM` (чутливість) та `MAX_CM` (дальність) у `lib/FlyDefense/src/fly/Sonar.h`. Якщо малі цілі помилково вважаються великими, збільшіть `WIDE_SPAN`.
4. Налаштувати провисання струменя: стріляти в ціль на 20 і 50 см і підбирати свій профіль ствола `fly::Nozzle::Profile {тривалість_мс, сотих_градуса_на_см}`, поки струмінь не лягає в точку. `TILT_UP_SIGN` (`Sonar.h`) залежить від того, як стоїть серво.
5. Щось переставили в кімнаті — натиснути RECAL.

## Прошивка — ключові рішення

- **Кути в десятих градуса** та `writeMicroseconds`. Пауза на доворот рахується з кута повороту (~2 мс/°), а не фіксована.
- **Пінг лише після того, як ECHO опуститься.** Якщо ехо немає, HC-SR04 тримає ECHO у HIGH ~38 мс і ігнорує новий тригер. Тому `pingCm()` спершу чекає LOW (не довше 50 мс). Без цього на відкритих ділянках губився кожен другий вимір.
- **Ширина об'єкта як суцільна смуга.** Стара перевірка (≥2 з ±2 сусідів) бракувала майже кожну справжню муху, бо пелюстка накриває кілька клітинок. Крім того, вона пропускала руку, на яку скан натрапив з краю.
- **Кеш скану.** Кожна клітинка запам'ятовується разом із часом виміру (`lastScan`). Сусідів, яких змійка пройшла менш ніж `FRESH_MS` тому, беремо з пам'яті.
- Поправки прицілу рахуються в `int` і обмежуються до приведення типу. Кулдауни порівнюються через різницю `millis()`.
- **Постріл — лише через модуль `Turret`**, і для сонара, і для камери. Сонар просить турель вистрілити в точку, а та стріляє лише коли: ARM увімкнено, серво доїхало, дозвіл свіжий (≤150 мс), немає блокування великого об'єкта (3 с), не вичерпано серію (3 постріли, далі кулдаун 2,5 с). Вимкнення ARM зупиняє помпу чи клапан посеред пострілу.
- **Очікування не зупиняє турель.** Сонар блокуючий, але чекає лише через `base.wait()`, тож таймінг пострілу (120 / 50 мс) витримується з точністю до мілісекунди.

## Тести

`pio test -e native` (потрібен g++ у PATH) запускає тести модулів бібліотеки на макеті Arduino API:
- **симуляцію збірки FlySonar:** віртуальна кімната, модель пелюстки, 8 положень мухи, рука на 30 і 50 см, ціль у польоті, режим SAFE;
- **збірку «турель + очі»:** протокол, серії, кулдаун, блокування великого об'єкта, застарілі команди, «сміття» на лінії, ARM;
- **турель, основу, хлопавку й зір** (синтетичні кадри).

## Ще апгрейди

- **Крокові двигуни** NEMA17 + TMC2209 замість серв: ~0,1° без мертвої зони й люфту. Потрібні кінцевики для хомінгу; у прошивці поки не реалізовано.
- **Шкідники поза зоною дії.** Фільтр «великого об'єкта» захищає руки й тварин, але це все ж водомет. Не залишайте ARM увімкненим біля людей, які не в курсі.
- **Стереосонар / аналіз ехо** (окремі 40 кГц трансд'юсери + ESP32 з АЦП): доплер від крил, реакція ~30 мс. Для мухи; мошку це все одно не покриває.

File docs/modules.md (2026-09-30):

# Модульна система: основа + модулі

Будь-який пристрій fly-defense складається з **основи** і **модулів**. Спершу збирається основа. Потім до неї підключаються модулі: в залізі — роз'ємами JST-XH, у прошивці — двома рядками коду. Три готові пристрої (FlyClap, FlySonar, FlySonar ESP32) — лише типові комбінації цих модулів. Можна зібрати свою.

```
                ┌──────────────── ОСНОВА ────────────────┐
                │ плата (Uno / Nano / ESP32-CAM)         │
                │ живлення 12 В → DC-DC 5 В              │
                │ тумблер ARM · статус-LED · бузер       │
                │ силові виходи (MOSFET + діод)          │
                └──┬─────────┬─────────┬─────────┬───────┘
          сенсори  │         │ серви   │ сила    │ зв'язок
        (XH-4/XH-6)│  (3-pin servo)    │ (XH-2)  │ (XH-3)
                   ▼         ▼         ▼         ▼
            завіса, сонар  pan-tilt  соленоїд,  інша плата
            кінцевик, RECAL           помпа,    ("очі")
                                      клапан
```

## Прошивка: бібліотека FlyDefense

Проєкт — звичайний проєкт PlatformIO з фреймворком Arduino. Модулі лежать у бібліотеці `lib/FlyDefense`, а кожен пристрій — це маленька прошивка в `src/<назва>/main.cpp`, що збирає його з модулів:

```cpp
#include <Arduino.h>
#include <FlyDefense.h>

fly::Base base(A0, 13);                    // основа: тумблер ARM, статус-LED
fly::IrCurtain curtain(4, 5, 6, 7);        // модуль-тригер
fly::ClapLatch clap(curtain, 9, 10, 8);    // модуль-виконавець

void setup() {
  base.add(curtain);
  base.add(clap);
  base.begin();
}

void loop() { base.update(); }
```

### Збірка

Відкрийте репозиторій у PlatformIO й виберіть середовище: `pio run -e flyclap -t upload` (див. [README](../README.md#збірка)). Кожне середовище в `platformio.ini` збирає одну прошивку з `src/`. Для своєї збірки є шаблон `src/mybuild` і середовище `mybuild`.

### Основа (`fly::Base`)

Основа є в кожній збірці й відповідає за безпеку:

- **Тумблер ARM** (до GND) — єдиний дозвіл на постріл для всіх модулів. Вимкнення миттєво зупиняє все: закриває клапан, знеструмлює соленоїд, відводить серво.
- **Реєстр пінів і таймерів.** Якщо два модулі хочуть один пін або таймер, у Serial з'явиться, наприклад, `CONFIG ERROR: pin 9 wanted by Turret, already used by ClapLatch`, і пристрій не озброїться, доки конфігурацію не виправлять.
- **Статус-LED** — однаковий для всіх пристроїв:

| LED | Значення |
|---|---|
| коротке мигання раз на 2 с | SAFE: ARM вимкнено, пристрій живий |
| горить | ARM, усе готово |
| повільно блимає | ARM, модуль зайнятий (взводиться, калібрується, чекає чистої завіси) |
| швидко блимає | аварія, помилка конфігурації або немає зв'язку з «очима» |

- **Бузер** (необов'язковий): `base.buzzer(pin)` — пасивний (тон), `base.buzzer(pin, true)` — активний.
- **Лог** у Serial на 115200.

## Каталог модулів

| Модуль | Роль | Що підключається | Плати | Роз'єми |
|---|---|---|---|---|
| `IrCurtain` | тригер | ІЧ-завіса з 4 променів: LM339 або TSSP4038 | AVR | XH-6 приймачі, XH-3 випромінювачі |
| `ClapLatch` | виконавець | засувка-хлопавка: соленоїд, серво взведення, кінцевик | AVR | XH-2 соленоїд, servo, XH-4 кінцевик |
| `Turret` = `PanTilt` + `Nozzle` | виконавець | pan-tilt на двох сервах + помпа або клапан | AVR, ESP32 | 2× servo, XH-2 ствол |
| `Sonar` | сенсор для `Turret` | HC-SR04 на голові турелі, кнопка RECAL | AVR, ESP32 | XH-4 сонар, XH-4 кнопка |
| `CameraEyes` | сенсор для `Turret` або `LinkOut` | камера ESP32 над підсвіченим фоном | ESP32 з PSRAM | — (камера на платі) |
| `LinkOut` | зв'язок | передає рішення сенсора на іншу плату | ESP32 (будь-який UART) | XH-3 зв'язок |
| `EyesLink` | зв'язок | приймає команди від `LinkOut` і наводить `Turret` | AVR, ESP32 | XH-3 зв'язок |

Сенсори турелі не знають, хто стріляє: `CameraEyes` однаково віддає рішення турелі на цій же платі (`Turret`) або Arduino по дроту (`LinkOut` → `EyesLink` → `Turret`). Постріл завжди проходить через `Turret`, тому правила безпеки однакові для всіх джерел цілей: ARM, доворот серв, свіжий дозвіл, серія з 3 пострілів, кулдаун, пауза після великого об'єкта.

### Типові збірки

| Прошивка | Плата | Модулі | Середовище PlatformIO |
|---|---|---|---|
| `src/flyclap` | Uno / Nano | `IrCurtain` + `ClapLatch` | `flyclap`, `flyclap_tssp`, `flyclap_nano` |
| `src/flysonar` | Uno / Nano | `Turret` + `Sonar` | `flysonar`, `flysonar_nano` |
| `src/flysonar_turret` | Uno / Nano | `Turret` + `EyesLink` | `flysonar_turret`, `flysonar_turret_nano` |
| `src/flysonar_eyes` | ESP32-CAM / S3 | `CameraEyes` + `LinkOut` | `flysonar_esp32_eyes`, `flysonar_esp32_s3_eyes` |
| `src/flysonar_esp32` | ESP32-CAM / S3 | `Turret` + `CameraEyes` | `flysonar_esp32`, `flysonar_esp32_s3` |
| `src/mybuild` | будь-яка | шаблон своєї збірки | `mybuild` |

## Залізо: роз'єми JST-XH

Усі модулі підключаються до основи роз'ємами **JST-XH (крок 2,5 мм)**: вони не вставляються навпаки, тримаються від вібрації хлопавки і дешеві. Різна кількість контактів у різних типів роз'ємів не дає переплутати, наприклад, силовий вихід 12 В із сенсором. Серви лишаються на своєму стандартному 3-pin роз'ємі: він є на кожній серві.

Основа і модулі: роз'єми JST-XH

Контакт 1 позначений на платі трикутником. Земля — завжди контакт 1 (крім силового виходу P). На схемах підключення кожен сигнал має зелену мітку роз'єму й контакту: `B·3` — роз'єм B, контакт 3.

| Тип | Роз'єм | 1 | 2 | 3 | 4 | 5 | 6 |
|---|---|---|---|---|---|---|---|
| **P** — силовий вихід | XH-2 | +12 В | OUT (стік MOSFET) | | | | |
| **L** — зв'язок між платами | XH-3 | GND | TX | RX | | | |
| **E** — випромінювачі завіси | XH-3 | GND | +5 В | CARRIER (несуча TSSP) | | | |
| **S** — сенсор / кнопка | XH-4 | GND | +5 В | SIG1 | SIG2 | | |
| **B** — приймачі завіси | XH-6 | GND | +5 В | B1 | B2 | B3 | B4 |
| **servo** | 3-pin 2,54 | GND (коричневий) | +5 В з DC-DC (червоний) | сигнал (помаранчевий) | | | |

- **P (силовий вихід).** MOSFET (IRLZ44N для 5 В логіки, AO3400 для ESP32) і захисний діод 1N5819 паралельно навантаженню стоять **на основі**. Тож соленоїд, помпа чи клапан — це просто навантаження на двох дротах. Для соленоїда понад 2 А використовуйте гвинтову клему замість XH-2. Біля соленоїда — електроліт 1000–2200 мкФ.
- **L (зв'язок).** TX однієї плати з'єднується з RX іншої, тож кабель перехресний (2↔3). Живлення по L не передається: кожна плата живиться від свого DC-DC, спільна лише земля. Логіка ESP32 — 3,3 В; Arduino приймає її на RX напряму.
- **S (сенсор).** HC-SR04: SIG1 = TRIG, SIG2 = ECHO. Кінцевик і кнопка: SIG1 на GND, SIG2 не використовується. На ESP32 ECHO сонара (5 В) заводьте через дільник 1 кОм / 2 кОм.
- **servo.** Живлення серв — від DC-DC 5–6 В ≥3 А, не від плати, з електролітом 470–1000 мкФ поруч із роз'ємами.

### Роз'єми типових збірок

| Роз'єм основи | FlyClap | FlySonar | FlySonarTurret | FlySonar ESP32 (AI-Thinker) |
|---|---|---|---|---|
| B (XH-6) | D4–D7 | | | |
| E (XH-3) | +5 В / D3 (TSSP) | | | |
| S1 (XH-4) | кінцевик → D8 | сонар → D2 / D3 | | |
| S2 (XH-4) | | RECAL → D4 | | |
| servo 1 | взведення → D10 | PAN → D9 | PAN → D9 | PAN → GPIO14 |
| servo 2 | | TILT → D10 | TILT → D10 | TILT → GPIO15 |
| P1 (XH-2) | соленоїд ← D9 | помпа / клапан ← D5 | помпа / клапан ← D5 | клапан ← GPIO13 |
| L (XH-3) | | | RX ← D0 | (роль «очі»: TX GPIO14) |
| на основі | ARM A0, LED D13, бузер D11 | ARM A0, LED D13 | ARM A0, LED D13 | ARM GPIO12, LED GPIO33 |

### Корпус основи (3D-друк)

Основа живе в коробці під плату 5 × 7 см. У її стінці — вікна під кутові вилки JST-XH (S?B-XH-A), припаяні на краю плати, тож штекери модулів вставляються ззовні. Над вікнами — отвори під гніздо живлення, тумблер ARM і статус-LED.

| FlyClap: блок електроніки | FlySonar: коробка основи |
|---|---|
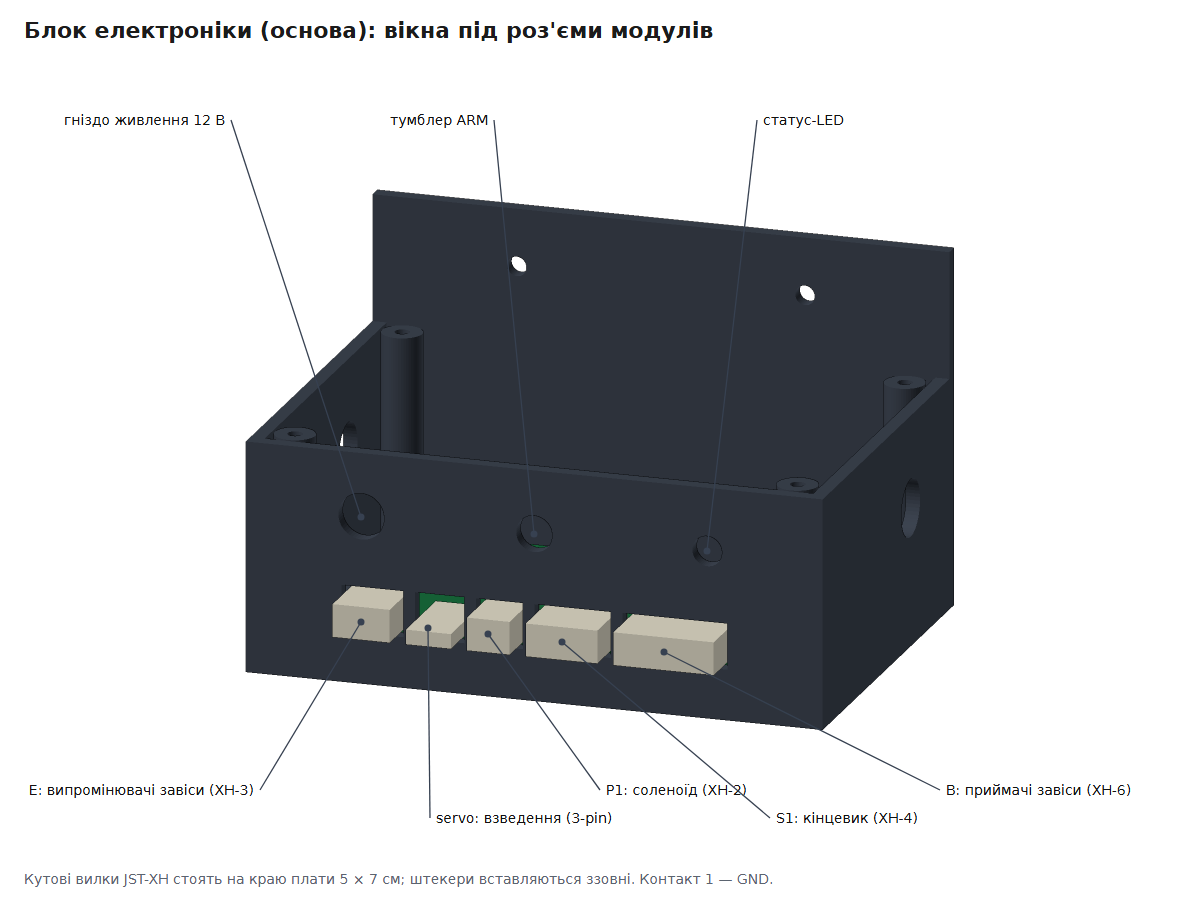
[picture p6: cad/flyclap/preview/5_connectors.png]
|  |  |

Обидві коробки генерує одна функція `base_box()` у [`cad/cadlib.py`](../cad/cadlib.py): вікна розкладаються зі списку роз'ємів збірки (`BASE_PORTS`), тож для своєї збірки достатньо змінити цей список. Файли для друку — у [cad/flyclap](../cad/flyclap/README.md) і [cad/flysonar](../cad/flysonar/README.md).

## Сумісність і обмеження

- **AVR (Uno / Nano):** `IrCurtain` використовує переривання PCINT, тому не поєднується з бібліотекою `SoftwareSerial`. Варіант TSSP займає Timer2 (несуча на D3), отже бузер має бути активним. D0/D1 зайняті USB-логом; `EyesLink` слухає D0.
- **ESP32:** `IrCurtain` і `ClapLatch` поки лише для AVR. Бузер лише активний, бо `tone()` конфліктує з тактуванням камери. Серви працюють на LEDC timer 2, максимум 4. Задача реального часу (tick модулів, 1 мс) виконується на ядрі 0.
- Одна основа — один `IrCurtain`.

## Свій модуль

Модуль — клас-нащадок `fly::Module`. Основа викликає його методи сама:

| Метод | Коли | Що робити |
|---|---|---|
| `begin(base)` | один раз на старті | зайняти піни (`base.claimPin`), налаштувати залізо; `false` — конфігурація неможлива |
| `tick(base, now)` | ~кожну 1 мс | швидка робота без блокувань: таймінги, опитування |
| `loop(base)` | з `loop()` | довга робота; чекати можна лише через `base.wait(ms)` |
| `disarm(base)` | ARM вимкнено | негайно зупинити все, що рухається чи стріляє |
| `health()` | постійно | `Ok`, `Busy` чи `Fault` — для статус-LED |

Каркас є в `src/mybuild/main.cpp`. Корисні точки розширення:

- **новий тригер для хлопавки** (п'єзо, ємнісний датчик, інша завіса) — нащадок `fly::Trigger`, який викликає `crossedFromIsr()`; `ClapLatch` працюватиме з ним без змін;
- **нове джерело цілей для турелі** — будь-який модуль, що викликає `aim()` / `bigObject()` в `fly::AimTarget`;
- **інший ствол** — свій `fly::Nozzle::Profile {тривалість_мс, провисання_×100}`.

Перш ніж пропонувати модуль у репозиторій, додайте тест у `test/test_<назва>/` за зразком наявних і запустіть `pio test -e native`.

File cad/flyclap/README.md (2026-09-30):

# FlyClap — корпус і механіка для 3D-друку

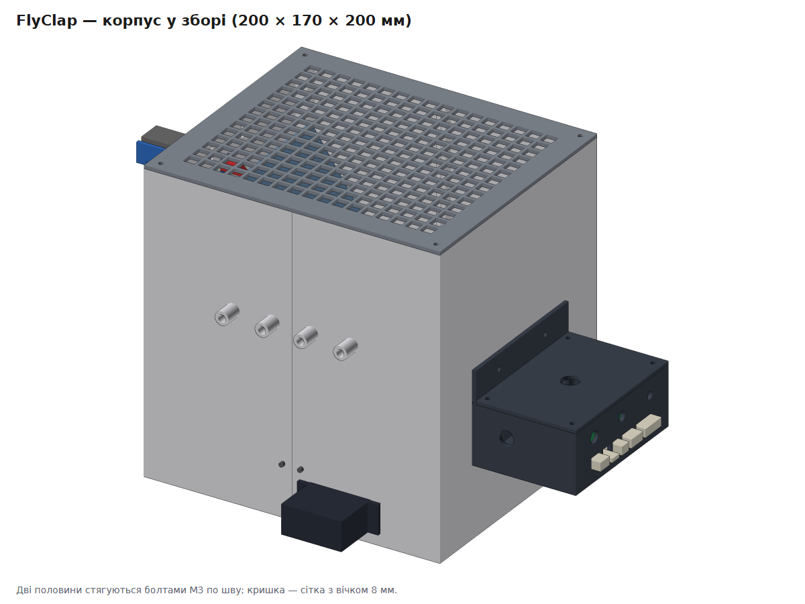
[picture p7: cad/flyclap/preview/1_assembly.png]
Корпус у зборі


Параметрична модель корпусу FlyClap під звичайний FDM-принтер зі столом **220 × 220 мм** (висота друку до 200 мм). Габарити корпусу **200 × 170 × 200 мм**. Він складається з двох половин, стягнутих болтами М3.

| Усередині (передню стінку зрізано) | Розріз спереду: механізм |
|---|---|
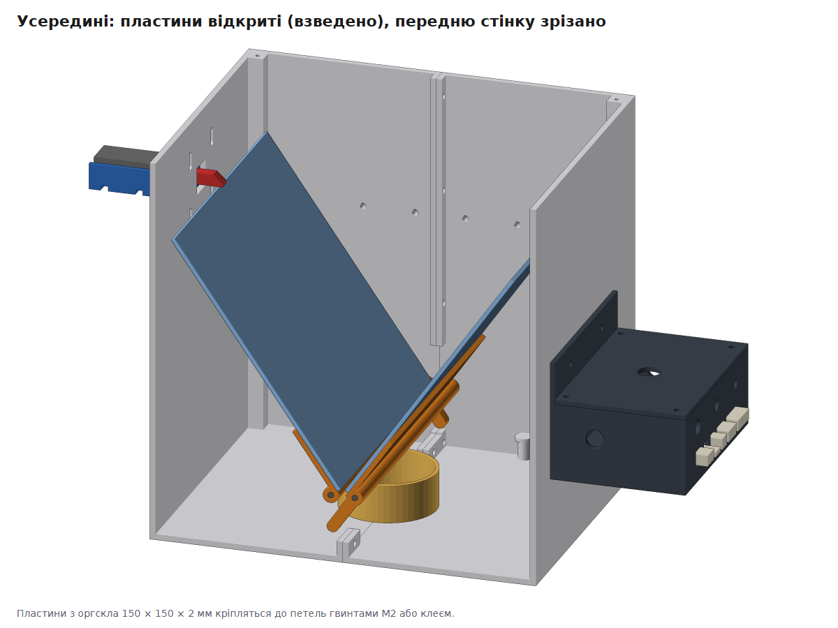
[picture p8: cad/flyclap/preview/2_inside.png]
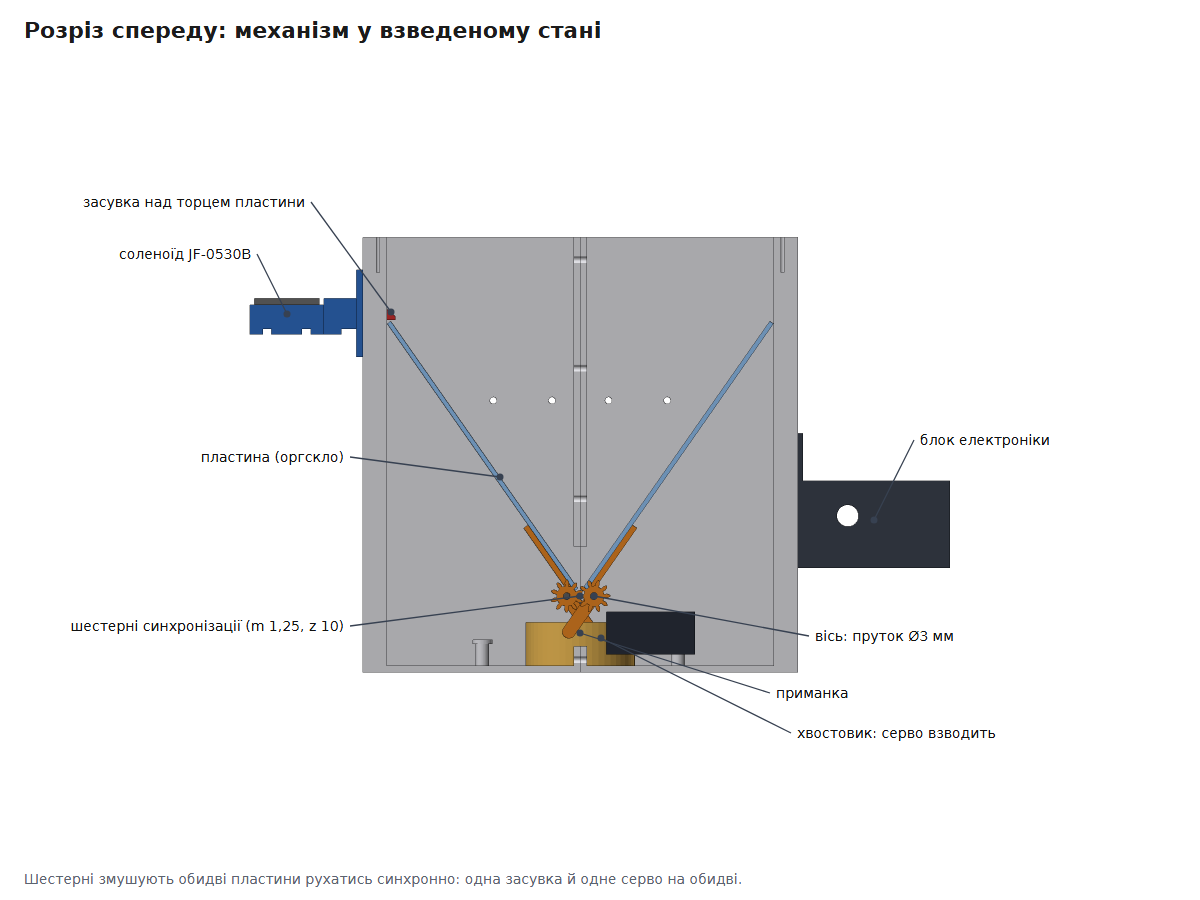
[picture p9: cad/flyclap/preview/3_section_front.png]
|  |  |

## Файли

| Що | Для чого |
|---|---|
| [`step/`](step/) | кожна деталь окремо у STEP. **Відкривається у FreeCAD** як тверде тіло (File → Open) |
| [`flyclap_assembly.step`](flyclap_assembly.step) | усе складання з кольорами й назвами деталей (пластини відкриті) |
| [`stl/`](stl/) | для слайсера (Cura, PrusaSlicer, OrcaSlicer) |
| [`flyclap_case.py`](flyclap_case.py) | параметрична модель (CadQuery), з неї згенеровано все вище |
| [`preview/`](preview/) | картинки |

### Як відкрити у FreeCAD
1. **File → Open** → `flyclap_assembly.step`. У дереві з'являться всі деталі з назвами й кольорами.
2. **File → Save As** → `FlyClap.FCStd`. Тепер це звичайний документ FreeCAD: деталі можна рухати, міряти, доробляти в Part Design (кнопка *Create body* поверх імпортованої деталі).
3. Окрему деталь для правок відкривайте з папки `step/`.

> Модель зроблена в CadQuery, на тому ж геометричному ядрі OpenCascade, що й FreeCAD. STEP передає точну геометрію, а не сітку трикутників. Параметричну історію (дерево операцій FreeCAD) через STEP не передати, тому розміри зручніше міняти у скрипті (див. нижче).

## Деталі для друку

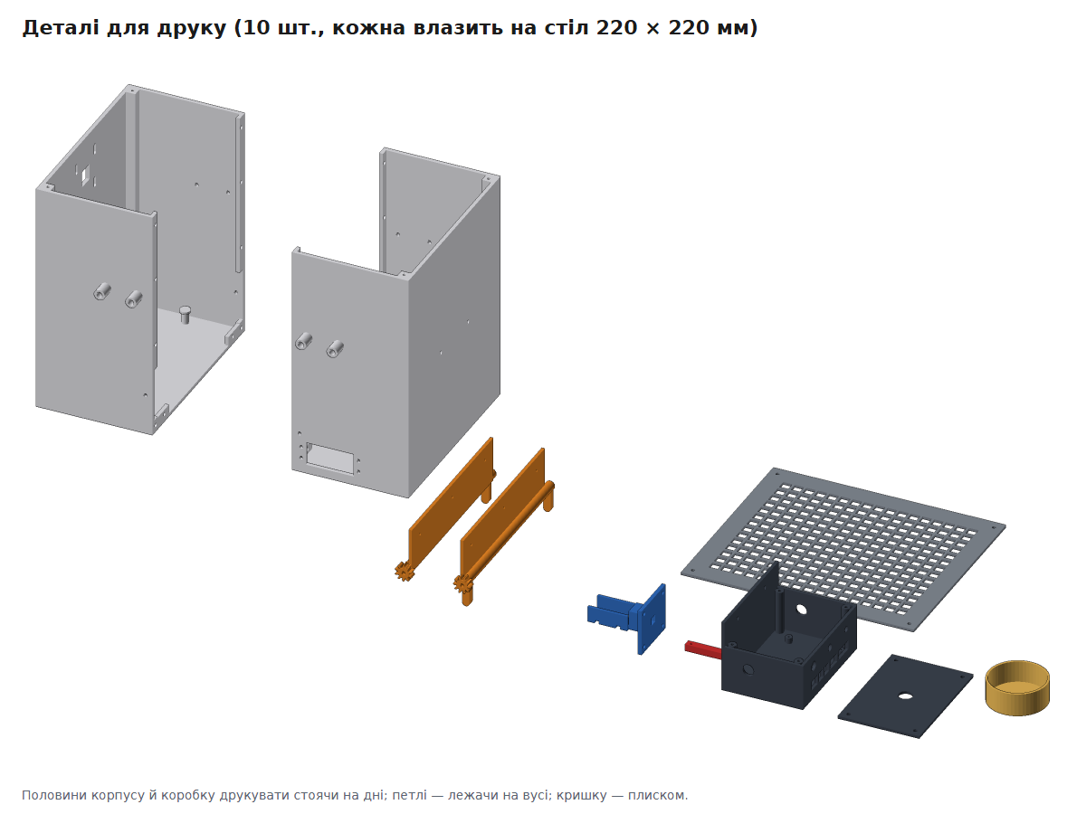
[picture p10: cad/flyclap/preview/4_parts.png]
Деталі


| Деталь | К-сть | Орієнтація на столі | Примітка |
|---|---|---|---|
| `shell_left`, `shell_right` | по 1 | стоячи на дні | 100 × 197 × 200 мм, підтримки не потрібні (вікно серви — міст 41 мм) |
| `lid_mesh` | 1 | плиском | сітка з вічком 8 мм |
| `hinge_left`, `hinge_right` | по 1 | лежачи на вусі | ліва й права **різні**: шестерні зсунуті на півзуба |
| `latch_mount` | 1 | плиском на монтажній пластині | люлька під соленоїд + напрямна засувки |
| `latch_bolt` | 1 | лежачи | засувка 6 × 6 зі скосом |
| `electronics_box`, `electronics_lid` | по 1 | коробка стоячи, кришка плиском | основа: плата 5 × 7 см, вікна під роз'єми JST-XH |
| `bait_cup` | 1 | стоячи | чашка для приманки ∅50 |

**Налаштування:** PETG (або PLA для приміщення), шар 0,2 мм, 3 периметри, заповнення 20 %. Для петель 4 периметри й 40 %: на них шестерні.

## Кріплення та інше (не друкується)

| Деталь | К-сть | Для чого |
|---|---|---|
| Оргскло 150 × 150 × 2 мм | 2 | пластини |
| Сталевий пруток ∅3 мм, довжина 176 мм (або шпилька М3 180 мм + 4 гайки) | 2 | осі петель |
| Гвинт М3 × 10 + гайка | 16 | шов половинок (10), кріплення засувки (4), блок електроніки (2) |
| Гвинт М3 × 8 (саморіз у пластик) | 8 | кришка-сітка (4), кришка блока (4) |
| Гвинт М2 × 8 + гайка | 6 | пластини до петель (по 3) |
| Гвинти з комплекту серви або М3 × 12 + гайки | 4 | MG996R |
| Канцелярські гумки або пружини розтягу | 2 | стягують пластини |
| Стяжки 3 мм | 2 | соленоїд у люльці |

## Складання

1. **Отвори.** Прочистіть отвори свердлом: 3,2 мм під М3, 3,3 мм у петлях (мають вільно обертатися на прутку).
2. **ІЧ-завіса.** Світлодіоди вставте в передні тунелі, фототранзистори в задні, **ззовні**, щоб деталь сиділа на зовнішньому кінці тунелю. Тоді тунель звужує промінь і захищає від стороннього світла. Зафіксуйте краплею клею.
3. **Пластини.** Просвердліть у пластинах по 3 отвори ∅2,2 навпроти отворів у вусі петлі й прикрутіть М2. Пластина лягає на вусо **з внутрішнього боку**, так що закриті пластини сходяться точно по центру.
4. **Петлі в половинки.** Кожна петля заходить у свою половину; пруток проходить крізь передню стінку, петлю й задню стінку.
5. **З'єднання половинок.** Обидві пластини поставте вертикально (закрито), зведіть половинки, щоб шестерні зачепились, і стягніть шов болтами. Покачайте пластини: вони мають розкриватися синхронно й без заїдань.
6. **Гумки.** Від отвору в задньому хвостовику петлі до стійки на дні своєї половини. Гумка має тягнути пластини до закриття.
7. **Серво.** MG996R вставте у вікно передньої стінки ззовні (вал усередину), закріпіть 4 гвинтами. Качалка має штовхати передній хвостовик правої петлі. Кути підберіть у прошивці: `SERVO_COCK_DEG` / `SERVO_REST_DEG`.
8. **Засувка.** Кріплення притуліть до лівої стінки ззовні, засувку вставте в напрямну скосом **вгору**, з'єднайте з якорем соленоїда (дріт або шпилька через отвір ∅2,2), соленоїд закріпіть стяжками. Пази в стінці дають ±3 мм по висоті. Виставте так, щоб у взведеному стані засувка ледь нависала над верхнім торцем лівої пластини.
9. **Кінцевик «взведено».** Мікроперемикач з важелем приклейте або прикрутіть біля засувки, щоб торець пластини натискав важіль у взведеному стані. Окремого кріплення в моделі немає: його положення залежить від конкретного перемикача.
10. **Блок електроніки.** Вушком до правої стінки, 2 × М3. Кришка сітки — 4 саморізи в кутові стійки. Кутові вилки JST-XH припаюйте на краю плати навпроти вікон (див. нижче).

## Роз'єми модулів (блок електроніки)

Вікна під роз'єми

Блок електроніки — це **основа** модульної системи ([docs/modules.md](../../docs/modules.md)): до неї роз'ємами підключаються завіса, засувка, серво й кінцевик. Плата 5 × 7 см стоїть на чотирьох стійках, зсунута до стінки з вікнами: між краєм плати й стінкою 0,6 мм. **Кутові вилки JST-XH (S2B/S3B/S4B/S6B-XH-A) і кутову гребінку серви припаюйте на самому краю плати, навпроти свого вікна**; тоді штекер модуля вставляється ззовні крізь стінку. Над вікнами — отвори під гніздо живлення ∅8, тумблер ARM ∅6,3 і статус-LED ∅5,2; у торцях — отвори ∅10 під силові дроти.

| Вікно (від переду до заду) | Роз'єм | Модуль |
|---|---|---|
| E | XH-3 | випромінювачі завіси (спереду корпусу) |
| servo | 3-pin 2,54 | серво взведення |
| P1 | XH-2 | соленоїд засувки |
| S1 | XH-4 | кінцевик «взведено» |
| B | XH-6 | приймачі завіси (ззаду корпусу) |

Набір і порядок вікон задає список `BASE_PORTS` на початку скрипта; саму коробку будує `base_box()` у [`cad/cadlib.py`](../cadlib.py).

## Що перевіряє скрипт

`python3 cad/flyclap/flyclap_case.py` (потрібно `pip install cadquery`) не лише генерує файли, а й перевіряє:
- кожна деталь влазить на стіл 220 × 220 × 250 мм і є одним цілим тілом (не розпадеться в слайсері);
- **деталі не перетинаються** ні у відкритому, ні в закритому стані, ні **на всьому ході пластин** (0…35° з кроком 5°). Це стосується шестерень, хвостовиків, пластин, стінок, чашки, серви, засувки, кришки й блока електроніки;
- засувка у взведеному стані справді нависає над торцем пластини;
- плата стає на стійки блока електроніки, а **кожен штекер проходить у своє вікно** (муляжі плати й штекерів не перетинаються з коробкою й кришкою).

Прапорці: `--no-export` (лише перевірки), `--preview` (перемалювати картинки; потрібні numpy і Chromium, шлях можна задати змінною `CHROME`).

## Змінити розміри

Усі розміри винесені на початок `flyclap_case.py`: розмір і кут розкриття пластин, стінки, положення ІЧ-променів, розміри серви й соленоїда, зазор FDM `CLR`. Змініть число, запустіть скрипт, і перевірки покажуть, чи нічого не зачіпається.

## Обмеження (чесно)

- **Вікна під роз'єми** розраховано за розмірами колодок JST-XH з даташита (ширина 2,5 × (n − 1) + 4,9 мм) із зазором 0,8 мм. Розташування вилок на платі залежить від вашого монтажу: приміряйте плату в коробці до пайки.

- **Розміри покупних деталей** (MG996R, JF-0530B, соленоїд і його якір) взято з типових креслень. **Звірте свої штангенциркулем** і за потреби виправте параметри `SERVO_*` / `SOL_*`: клони відрізняються на 0,5–2 мм.
- **Зв'язок засувки з якорем соленоїда** залежить від конкретного соленоїда: у моделі є лише отвір під шпильку.
- **Качалка серви** не змодельована: її довжину й кут підберіть по місцю.
- **Нічого не надруковано й не перевірено на залізі**: перевірки геометричні. Шестерні m 1,25 друкуються нормально соплом 0,4 мм, але перший раз варто надрукувати петлі окремо й перевірити зачеплення.
- **Висота 200 мм:** на принтерах з меншою висотою друку (Prusa MK3 — 210 мм, деякі — 180 мм) зменшіть `H` і `PLATE`.

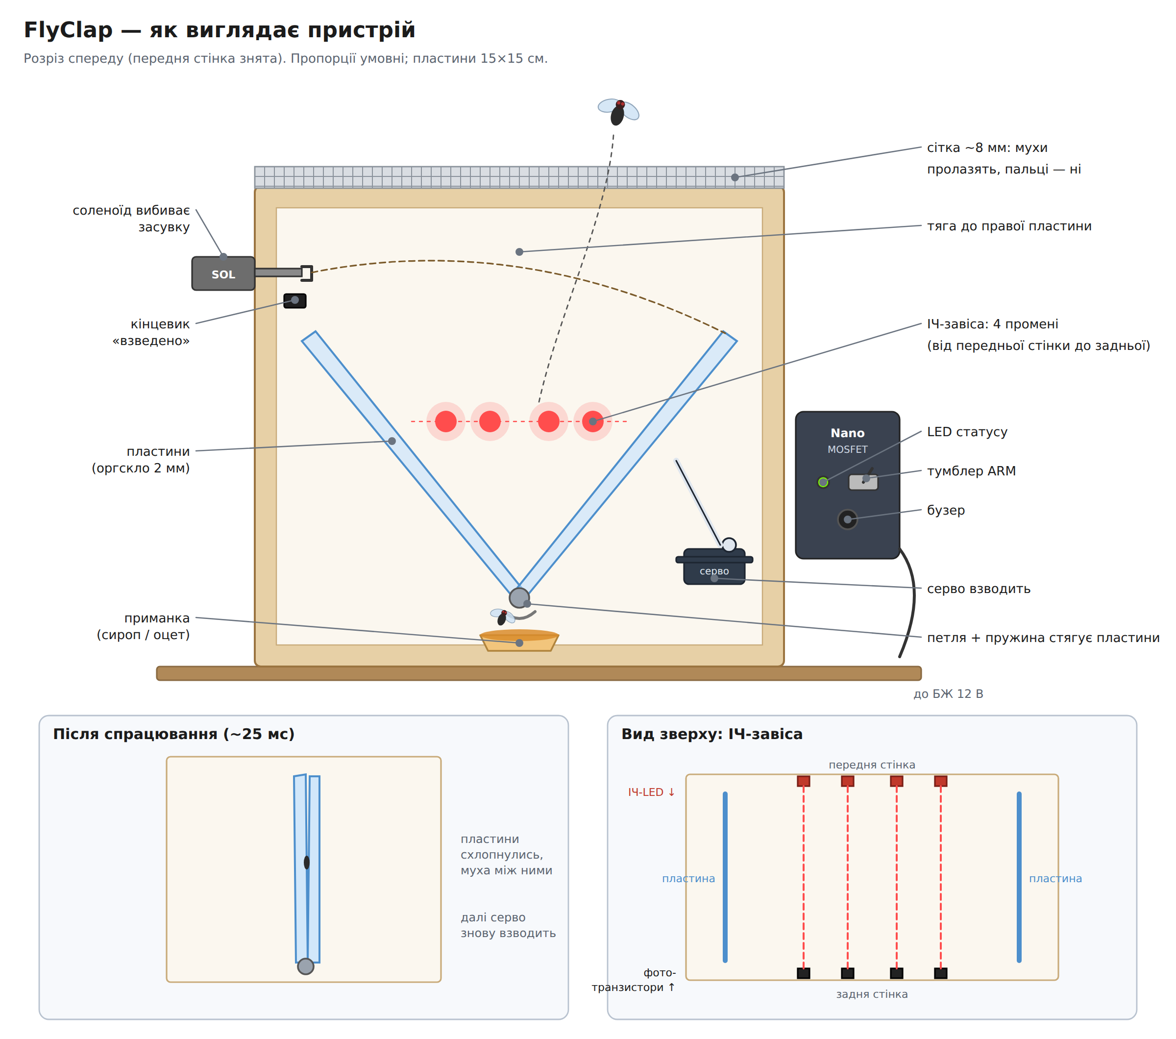
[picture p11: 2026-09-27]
schematics/png/flyclap-device.png

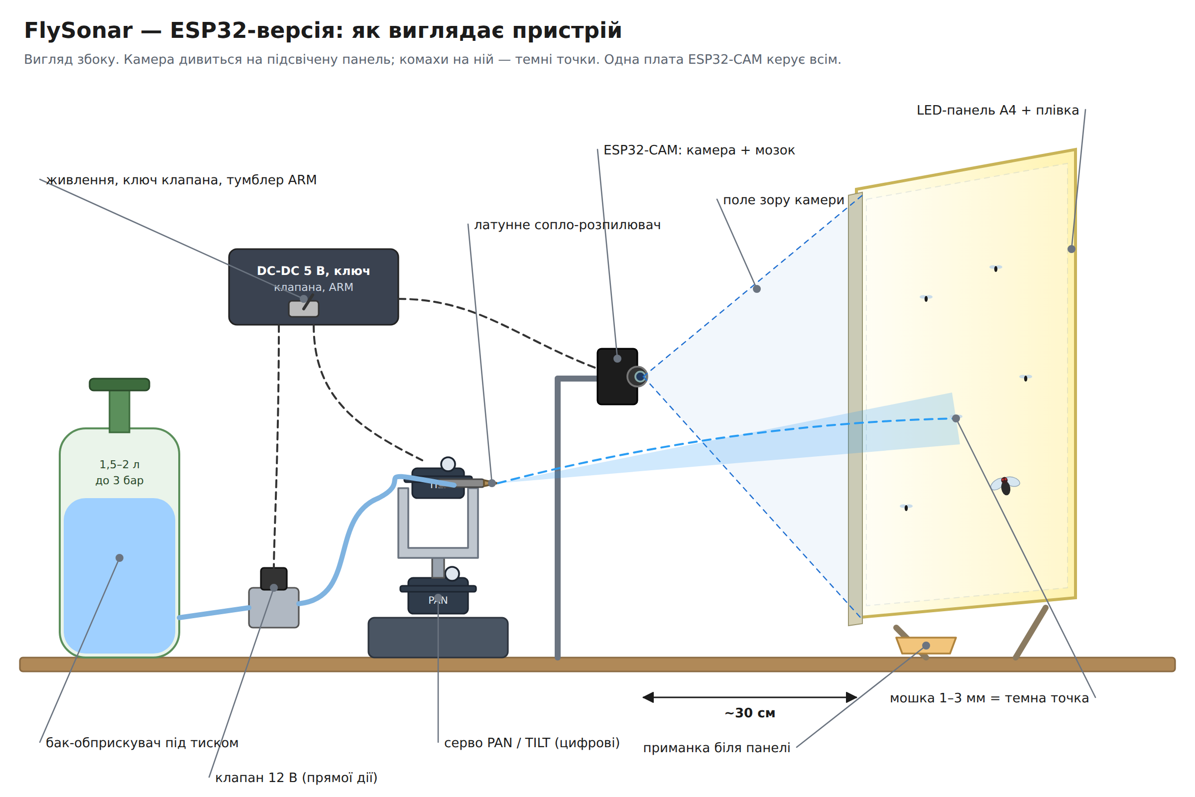
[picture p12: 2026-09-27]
schematics/png/flysonar-esp32-device.png

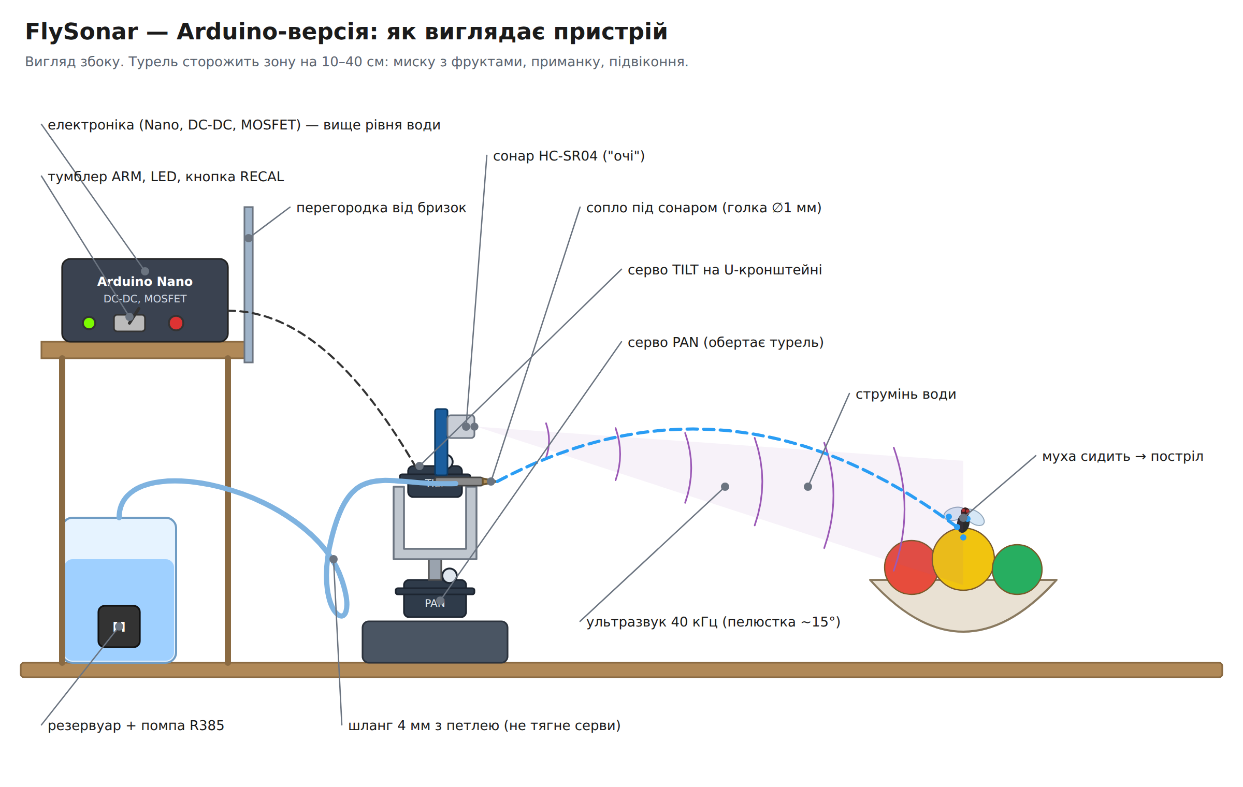
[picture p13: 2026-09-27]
schematics/png/flysonar-arduino-device.png

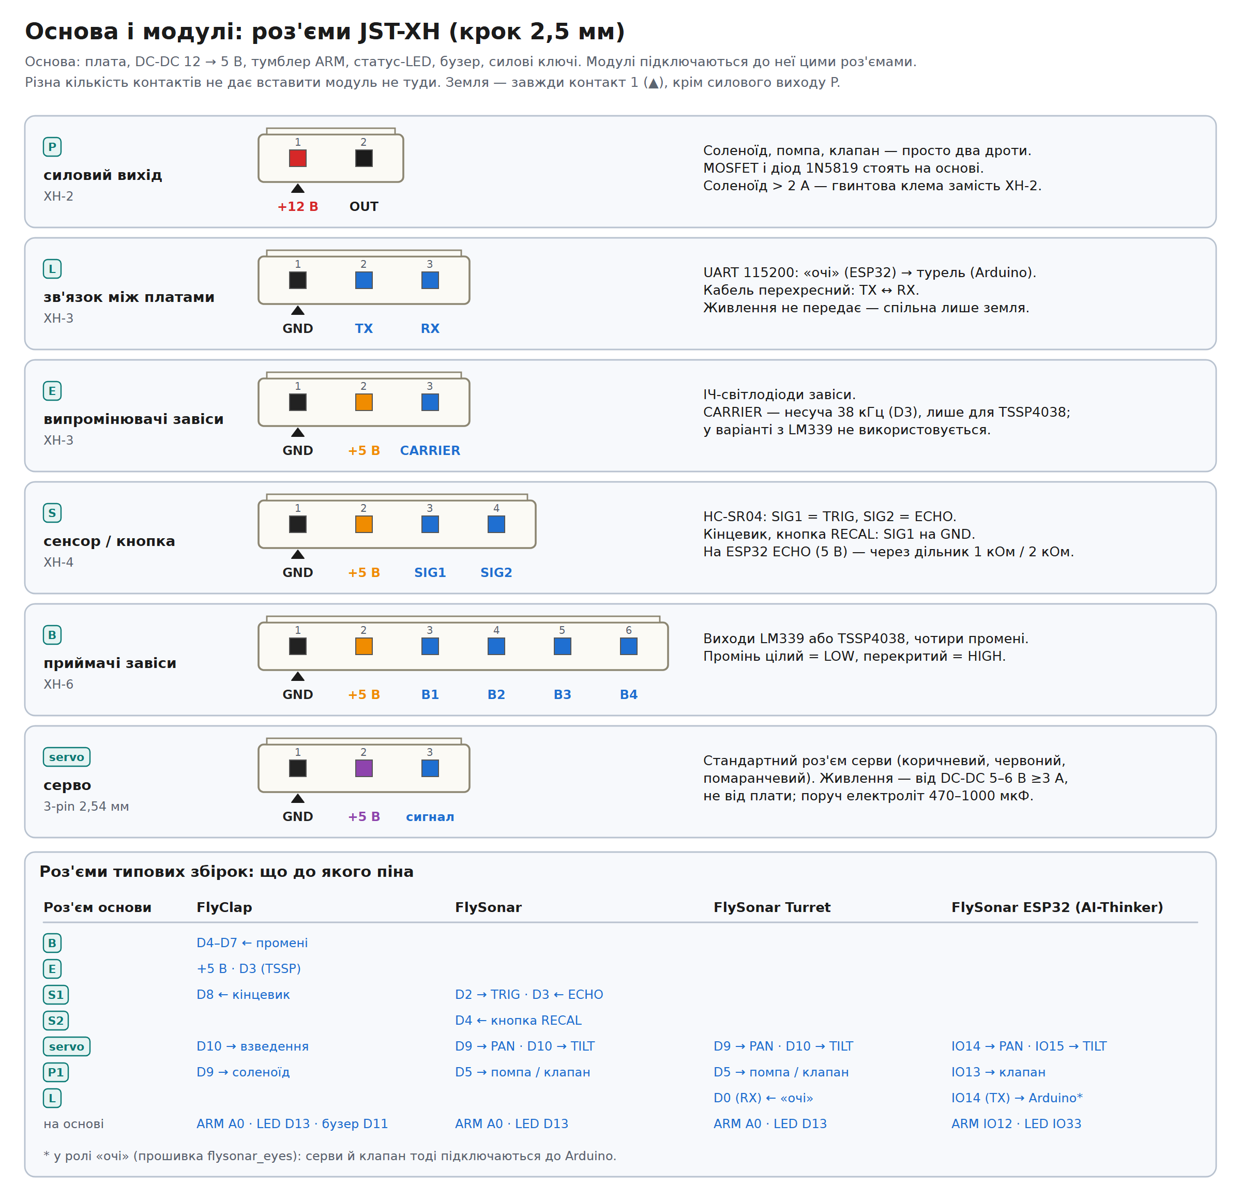
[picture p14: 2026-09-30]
schematics/png/modules-connectors.png

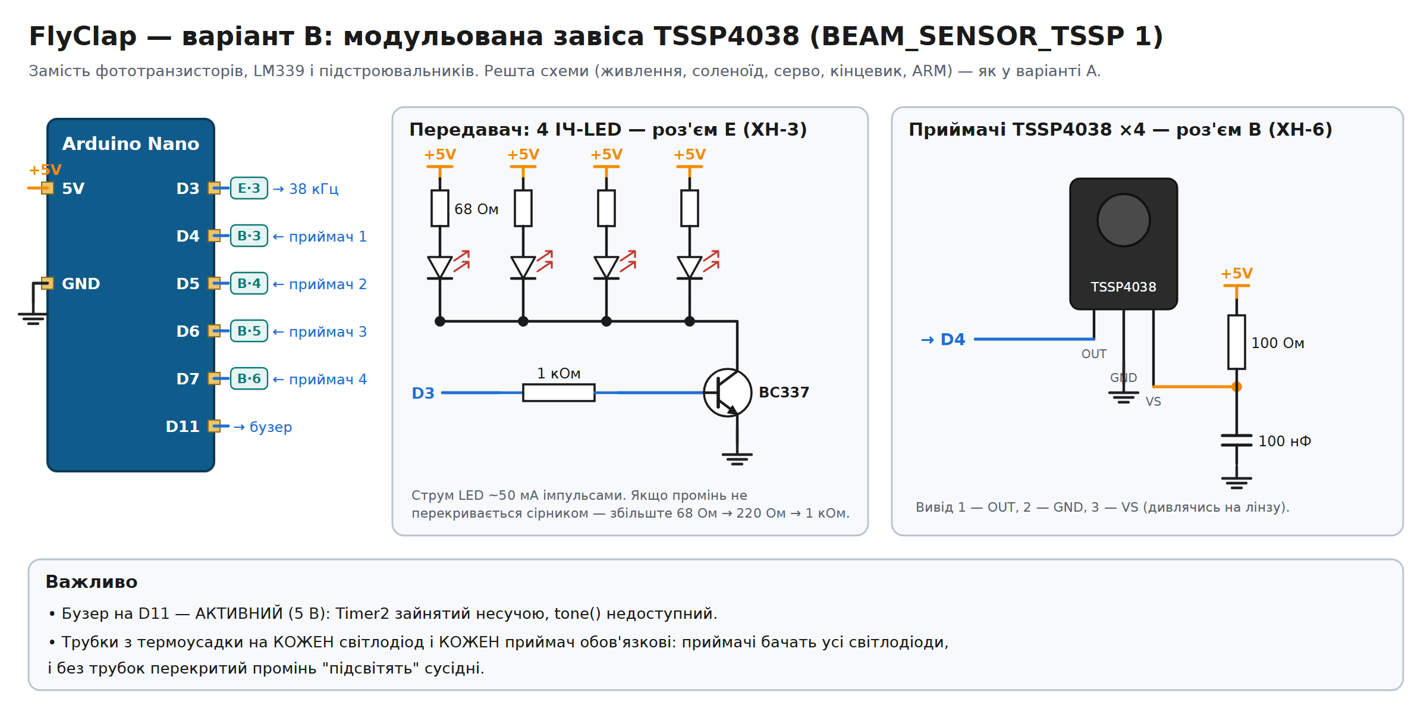
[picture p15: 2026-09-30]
schematics/png/flyclap-tssp.png

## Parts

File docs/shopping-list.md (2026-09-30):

# 🛒 Список покупок

Кожен пристрій нижче — **повний комплект**: якщо збираєте щось одне, купуйте лише його розділ і розділ «Витратні матеріали та інструменти». Кількості вказано із запасом там, де деталі легко спалити чи загубити. Подробиці підключення — у документації кожного проєкту.

| Пристрій | Що робить | Документація |
|---|---|---|
| [FlyClap](#1-flyclap) | ІЧ-завіса + пластини-хлопавка, реакція ~25 мс | [flyclap.md](flyclap.md) |
| [FlySonar — Arduino](#2-flysonar--arduino-версія) | турель із сонаром HC-SR04 і водометом, мухи, що сидять | [flysonar.md](flysonar.md) |
| [FlySonar — ESP32](#3-flysonar--esp32-версія) | турель на одній ESP32-CAM, бачить і мошку 1–3 мм | [flysonar-esp32.md](flysonar-esp32.md) |
| [Деталі для 3D-друку](#6-для-3d-друку-опційно) | пластик і кріплення, якщо друкуєте корпус FlyClap або турель FlySonar | [cad/flyclap](../cad/flyclap/README.md), [cad/flysonar](../cad/flysonar/README.md) |

> **З чого почати:** FlyClap — найпростіший і найнадійніший пристрій. Якщо потрібна турель, ESP32-версія точніша й бачить дрібних комах; Arduino-версія простіша в налагодженні, але ловить лише мух, що сидять.

## 1. FlyClap

### Контролер і живлення

| Деталь | К-сть | Примітка |
|---|---|---|
| Arduino Nano (ATmega328P, CH340) + USB-кабель | 1 | Або Uno R3 + Proto Shield |
| Макетна плата 5×7 см | 1 | |
| БЖ 12 В 2 А + гніздо DC 5.5×2.1 | 1 | |
| DC-DC понижувач XL4015 / LM2596 (5–6 В, ≥3 А) | 1 | Живлення серви |
| Електроліт 470–1000 мкФ 16 В | 1 | Біля серви |
| Електроліт 1000–2200 мкФ 25 В | 1 | Біля соленоїда |
| Кераміка 100 нФ | 5 | |
| Тумблер (ARM), світлодіод 5 мм + 330 Ом | 1 | |

### ІЧ-завіса — оберіть один варіант

**Варіант A — фототранзистори + LM339** (`BEAM_SENSOR_TSSP 0`, дешевше, треба налаштувати)

| Деталь | К-сть |
|---|---|
| ІЧ-світлодіод 940 нм (TSAL6200) | 6 |
| Фототранзистор TEFT4300 | 6 |
| Компаратор LM339 + панелька DIP-14 | 1 |
| Підстроювальний резистор 10 кОм (3296) | 4 |
| Резистор 150 Ом | 4 |
| Резистор 10 кОм | 8 |
| Резистор 1 МОм (гістерезис) | 4 |
| **Пасивний** п'єзо-бузер | 1 |

**Варіант B — TSSP4038** (`BEAM_SENSOR_TSSP 1`, не боїться сонця, без налаштування)

| Деталь | К-сть |
|---|---|
| ІЧ-світлодіод 940 нм (TSAL6200) | 6 |
| ІЧ-приймач TSSP4038 | 5 |
| Транзистор BC337 | 1 |
| Резистор 68 Ом | 4 |
| Резистор 100 Ом | 4 |
| Резистор 1 кОм | 1 |
| Кераміка 100 нФ | 4 |
| **Активний** бузер 5 В | 1 |

### Виконавча частина

| Деталь | К-сть | Примітка |
|---|---|---|
| Соленоїд 12 В push/pull, хід ~5 мм (JF-0530B) | 1 | |
| MOSFET IRLZ44N + резистори 100 Ом і 10 кОм | 1 | Ключ соленоїда |
| Діод Шотткі 1N5819 | 1 | Паралельно котушці |
| Сервопривід MG996R | 1 | Взводить механізм |
| Мікроперемикач з важелем (кінцевик) | 1 | |

### Механіка

> **Друкуєте корпус** ([cad/flyclap](../cad/flyclap/README.md))? Тоді петлі, засувка, корпус і сітка — надруковані, а з цього списку потрібні лише пластини, гумки, термоусадка й приманка. Пластик і кріплення — у [розділі 6](#6-для-3d-друку-опційно).

- [ ] Оргскло 2 мм / PET — 2 пластини 15×15 см
- [ ] 2–4 маленькі петлі
- [ ] Пружини розтягу або гумки
- [ ] Засувка (3D-друк або алюмінієвий кутик)
- [ ] Корпус (фанера / пластик / 3D-друк)
- [ ] Сітка з вічком ~8 мм
- [ ] Чорна термоусадка (трубки на сенсори)
- [ ] Приманка: сироп / оцет

## 2. FlySonar — Arduino-версія

### Електроніка

| Деталь | К-сть | Примітка |
|---|---|---|
| Arduino Nano (ATmega328P, CH340) + USB-кабель | 1 | Або Uno R3 + Proto Shield |
| Макетна плата 5×7 см | 1 | |
| HC-SR04 | 2 | Один запасний. **Не** JSN-SR04T |
| Серво MG90S (металеві шестерні) | 2 | |
| Pan-tilt кронштейн під SG90/MG90S | 1 | Або надрукувати: [розділ 6](#6-для-3d-друку-опційно) |
| MOSFET IRLZ44N + резистори 100 Ом і 10 кОм | 1 | Ключ помпи |
| Діод Шотткі 1N5819 | 1 | Паралельно помпі |
| БЖ 12 В 2 А + гніздо DC 5.5×2.1 | 1 | |
| DC-DC понижувач (5–6 В, ≥2 А) | 1 | Живлення серв |
| Електроліт 470–1000 мкФ 16 В | 1 | Біля серв |
| Кераміка 100 нФ | 3 | Біля HC-SR04 і Arduino |
| Тактова кнопка (RECAL) | 1 | |
| Тумблер (ARM), світлодіод 5 мм + 330 Ом | 1 | |

### Водомет

| Деталь | К-сть | Примітка |
|---|---|---|
| Помпа R385 12 В (або мембранна 5 В) | 1 | Або клапан + бак, див. [апгрейди](#4-апгрейди-точності-опційно) |
| Зворотний клапан 4 мм | 1 | Біля сопла |
| Силіконова трубка 4 мм | 1 м | |
| Голка / насадка ∅1 мм | 1 | Сопло |
| Резервуар (пляшка / контейнер) | 1 | |
| Пластиковий бокс / перегородка для електроніки | 1 | Захист від води |

## 3. FlySonar — ESP32-версія

Одна плата замість Arduino і сонара. HC-SR04 і Arduino **не потрібні**.

### Електроніка

| Деталь | К-сть | Примітка |
|---|---|---|
| ESP32-CAM AI-Thinker (OV2640, 4 МБ PSRAM) | 1 | Або Freenove ESP32-S3-WROOM CAM (USB вбудований, більше вільних пінів) |
| Програматор ESP32-CAM-MB (USB) | 1 | Лише для AI-Thinker |
| Цифрові мікросерво з металевими шестернями (напр. EMAX ES08MD II) | 2 | Точніші; MG90S теж працюють, але з мертвою зоною ~1° |
| Pan-tilt кронштейн під мікросерво | 1 | Або надрукувати: [розділ 6](#6-для-3d-друку-опційно) |
| MOSFET для 3,3 В логіки: модуль-ключ на AO3400, або AO3400 / IRLML6344 (SOT-23) | 1 | IRLZ44N від 3,3 В відкривається не повністю |
| Діод Шотткі 1N5819, резистори 100 Ом і 10 кОм | 1 | Діод паралельно клапану; 100 Ом у затвор, 10 кОм затвор→GND |
| БЖ 12 В 2 А + гніздо DC 5.5×2.1 | 1 | Клапан |
| DC-DC понижувач 5 В **≥3 А** | 1 | ESP32 і серви: ESP32-CAM дуже чутлива до просадок |
| Електроліт 1000 мкФ 16 В | 1 | Біля серв |
| Тумблер (ARM) | 1 | Статус-LED уже є на платі |

### Зір

| Деталь | К-сть | Примітка |
|---|---|---|
| LED-планшет для копіювання A4 (USB 5 В) | 1 | Підсвічений фон. A3 — більше поле, але гірша роздільність |
| Прозора плівка або оргскло 2 мм | 1 | Захист панелі від бризок, протирається |
| Жорсткий кронштейн для камери | 1 | Камера не повинна зсуватися після калібрування. Або надрукувати: [розділ 6](#6-для-3d-друку-опційно) |
| Чорна наліпка ∅3–5 мм | 1 | Маркер для калібрування |

### Водомет (клапан під тиском)

| Деталь | К-сть | Примітка |
|---|---|---|
| Садовий обприскувач під тиском 1,5–2 л | 1 | Бак + ручна помпа |
| Електромагнітний клапан 12 В нормально закритий, **прямої дії** | 1 | Пілотні (мембранні) клапани при малому тиску не відкриваються |
| Шланг і фітинги під тиск до 3 бар | — | |
| Латунне сопло-розпилювач 0,3–0,5 мм | 1–2 | Конус 2–4 см прощає залишкову похибку |
| Пластиковий бокс / перегородка для електроніки | 1 | Захист від води |

Замість клапана можна взяти помпу R385 як в Arduino-версії (`SHOOTER_VALVE 0`), але вона повільніша й менш точна.

## 4. Апгрейди точності (опційно)

**Для Arduino-версії:**

| Що | Навіщо |
|---|---|
| Водомет з розділу 3 (обприскувач + клапан + розпилювач) замість помпи | Струмінь за 5–10 мс замість 50–100 мс, менше провисає (`SHOOTER_VALVE 1`). Ключ IRLZ44N лишається: Arduino дає 5 В |
| Цифрові мікросерво замість MG90S | Приціл ~0,2–0,3° замість ~1° |
| ESP32-CAM + зір з розділу 3 | ESP32 працює як «очі», а стріляє Arduino (`flysonar_esp32_eyes` + `flysonar_turret`). HC-SR04 тоді не потрібен |

## 5. Витратні матеріали та інструменти

- [ ] **Роз'єми JST-XH (крок 2,5 мм)** (набір 2/3/4/6-pin: штекери, гнізда, контакти) і обжимка для них (SN-28B або аналог). Модулі підключаються до основи саме ними, див. [modules.md](modules.md#залізо-розєми-jst-xh). Можна купити готові кабелі з обжатими контактами
- [ ] Дроти Dupont, клемники, термоусадка, припій
- [ ] Паяльник + флюс
- [ ] Мультиметр — обов'язково для налаштування DC-DC (і підстроювальників FlyClap)
- [ ] Бокорізи, клейовий пістолет, стяжки

## 6. Для 3D-друку (опційно)

Потрібно, лише якщо друкуєте деталі з [cad/](../cad/). Покупні кронштейни, корпус і петлі з розділів вище тоді не потрібні.

### Пластик

| Що друкуєте | Скільки пластику | Примітка |
|---|---|---|
| Корпус FlyClap (10 деталей) | **0,8–1 кг** | стінки 3 мм друкуються майже суцільними — беріть повну котушку 1 кг |
| Турель FlySonar + кріплення камери | 0,1–0,2 кг | |
| Пробні петлі FlyClap | ~0,05 кг | раджу надрукувати спершу, щоб перевірити зачеплення шестерень |

PETG (міцніший, не боїться вологи й тепла) або PLA (для приміщення). Оцінка — за об'ємом моделей, реальна витрата залежить від заповнення в слайсері.

### Кріплення: корпус FlyClap

| Деталь | К-сть | Для чого |
|---|---|---|
| Оргскло 150 × 150 × 2 мм | 2 | пластини (вже є в розділі 1) |
| Сталевий пруток ∅3 мм, 176 мм (або шпилька М3 × 180 + 4 гайки) | 2 | осі петель |
| Гвинт М3 × 10 + гайка | 16 | шов половинок (10), засувка (4), блок електроніки (2) |
| Саморіз М3 × 8 | 8 | кришка-сітка (4), кришка блока електроніки (4) |
| Гвинт М2 × 8 + гайка | 6 | пластини до петель |
| Гумки або пружини розтягу | 2 | стягують пластини |
| Стяжки 3 мм | 2 | соленоїд у люльці |

### Кріплення: турель FlySonar

| Деталь | К-сть | Для чого |
|---|---|---|
| Гвинт / саморіз М3 × 12 | 1 | вісь нахилу головки |
| Гвинти М3 або шурупи 3,5 мм | 4 | основа до дошки |
| Латунна трубка / голка ∅4 мм | 1 | сопло (для силікону 4 × 6 змініть `NOZ_D` у моделі) |
| Стяжки 3 мм | 1–3 | сопло; ще 2 — плата ESP32-CAM |
| Гвинт М3 × 16 + гайка | 1 | лише ESP32: вісь нахилу камери |
| Гвинти М4 | 2 | лише ESP32: стійка камери до дошки |

Гвинти для серв (вушка, качалки) є в їхньому комплекті.

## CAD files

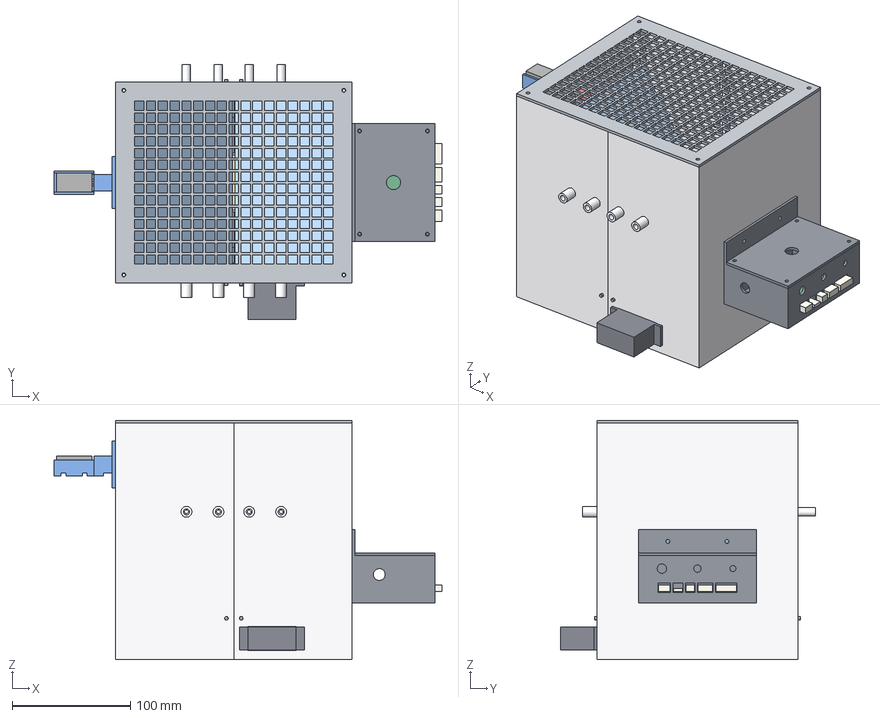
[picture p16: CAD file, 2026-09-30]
cad/flyclap/flyclap_assembly.step
328.0 x 215.9 x 202.4 mm
shell_right
shell_left
lid_mesh
hinge_right
hinge_left
plate_right
plate_left
rod_right
rod_left
latch_mount
latch_bolt
electronics_box
electronics_lid
base_pcb
base_plugs
bait_cup
servo_MG996R
solenoid_JF0530B

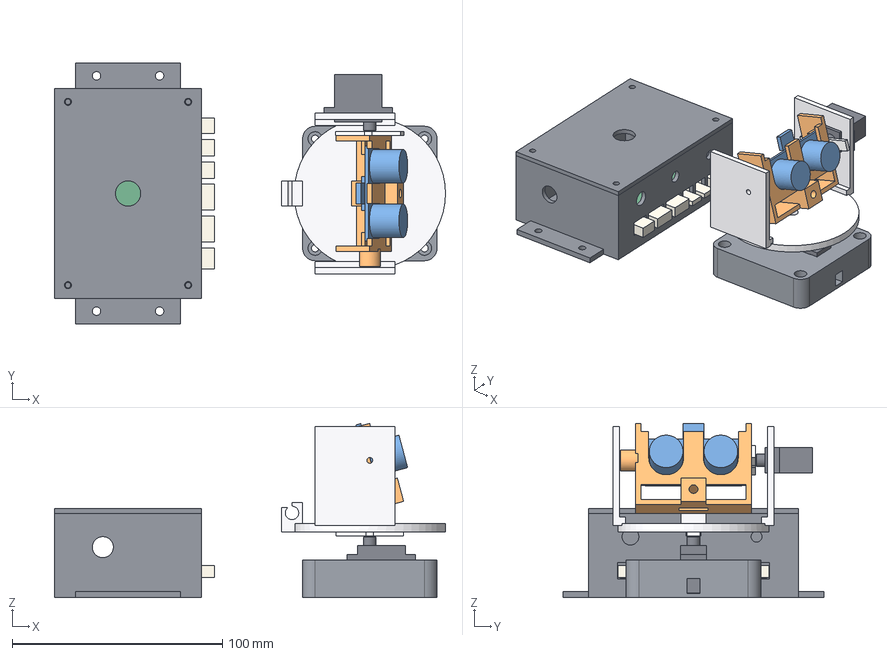
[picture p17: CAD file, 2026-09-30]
cad/flysonar/turret_arduino_assembly.step
186.0 x 124.0 x 82.9 mm
base
servo_pan
horn_pan
yoke
servo_tilt
horn_tilt
head
hcsr04
electronics_box
electronics_lid
base_pcb
base_plugs

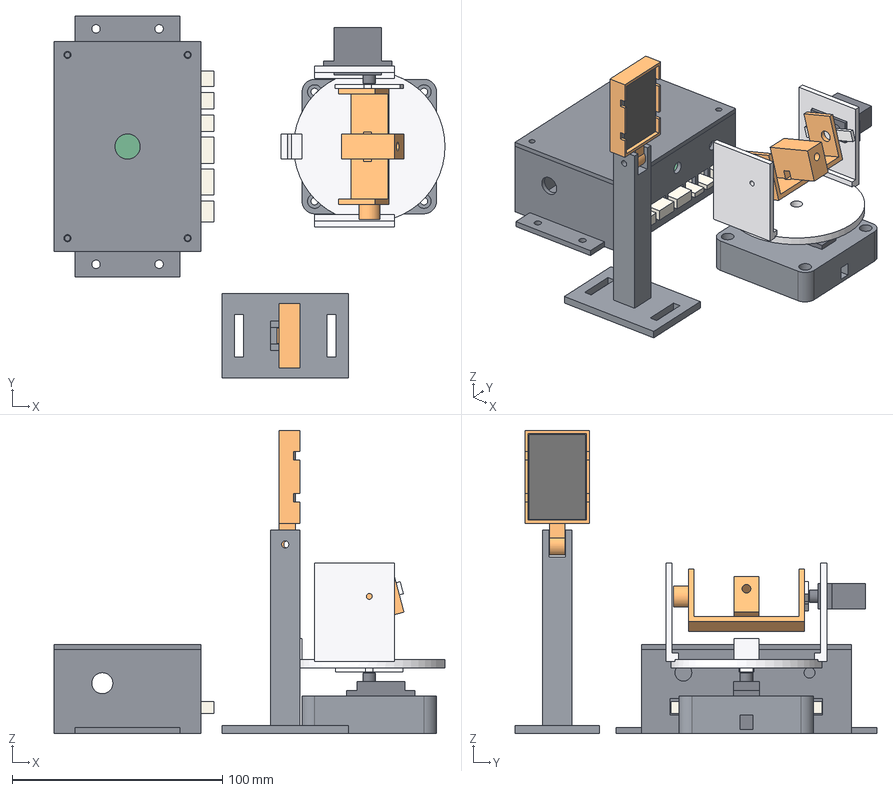
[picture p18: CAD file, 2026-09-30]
cad/flysonar/turret_esp32_assembly.step
186.0 x 172.0 x 144.3 mm
base
servo_pan
horn_pan
yoke
servo_tilt
horn_tilt
head
electronics_box
electronics_lid
base_pcb
base_plugs
camera_post
camera_cradle
esp32cam

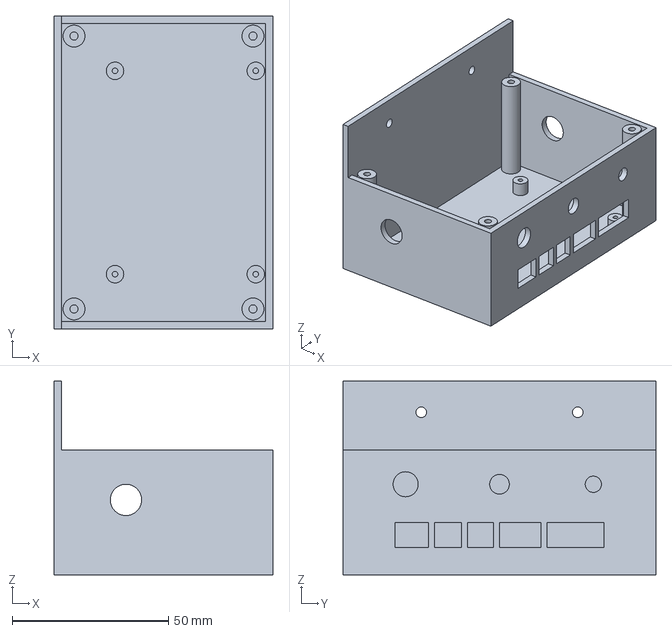
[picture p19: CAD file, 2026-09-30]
cad/flyclap/step/electronics_box.step
70.0 x 100.0 x 62.0 mm

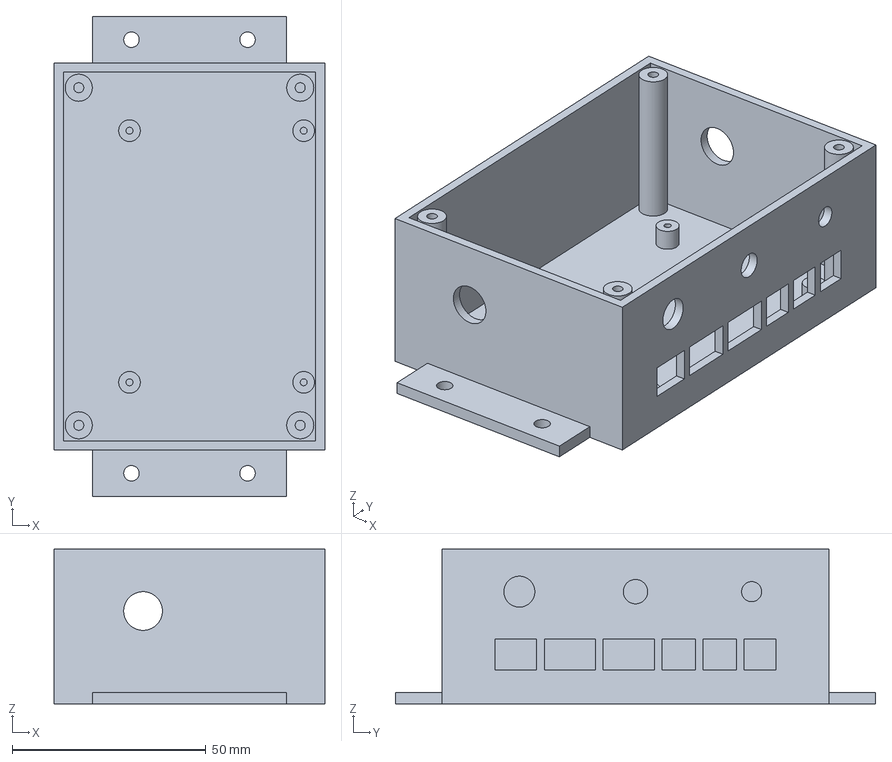
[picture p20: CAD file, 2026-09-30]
cad/flysonar/step/electronics_box.step
70.0 x 124.0 x 40.0 mm

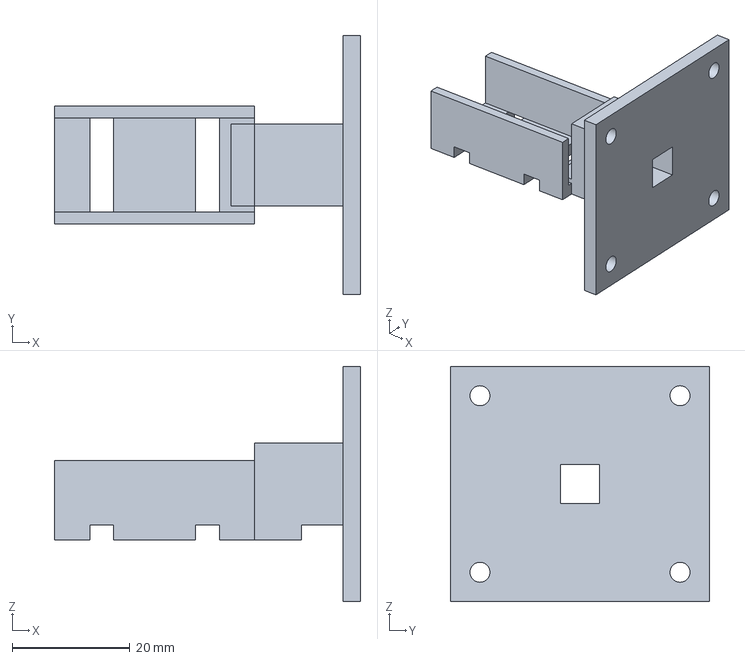
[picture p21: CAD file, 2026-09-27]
cad/flyclap/step/latch_mount.step
52.0 x 44.0 x 40.0 mm

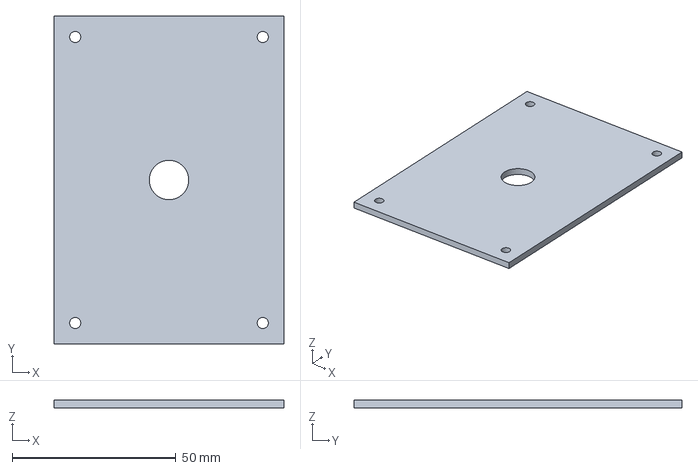
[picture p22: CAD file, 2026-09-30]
cad/flysonar/step/electronics_lid.step
70.0 x 100.0 x 2.40 mm

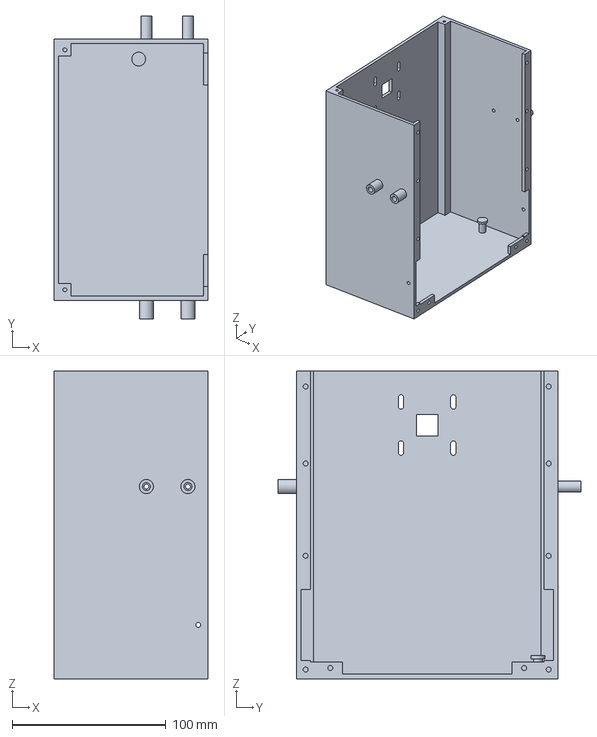
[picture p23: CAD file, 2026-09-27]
cad/flyclap/step/shell_left.step
100.0 x 197.0 x 200.0 mm

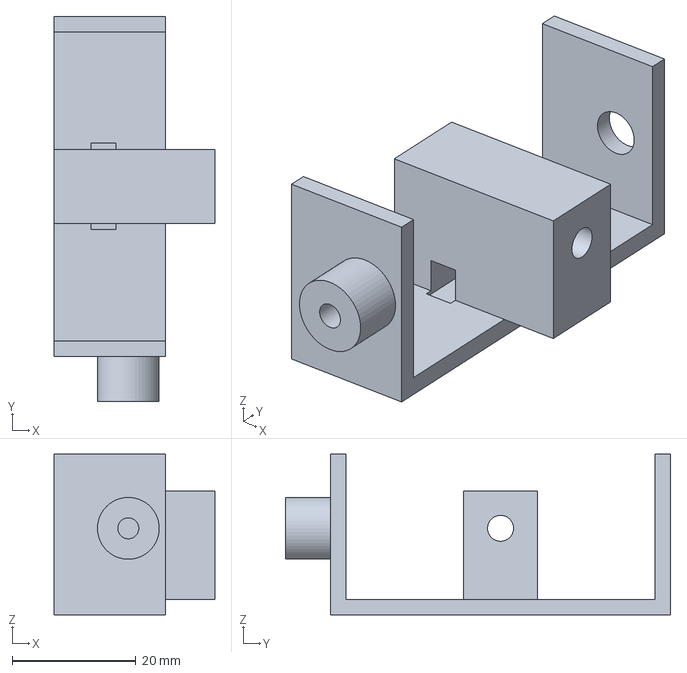
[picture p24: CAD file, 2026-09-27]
cad/flysonar/step/head_nozzle.step
26.0 x 62.3 x 26.0 mm

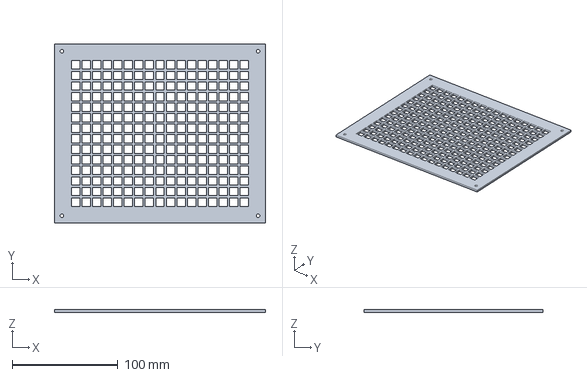
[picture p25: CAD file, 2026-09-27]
cad/flyclap/step/lid_mesh.step
200.0 x 170.0 x 2.40 mm

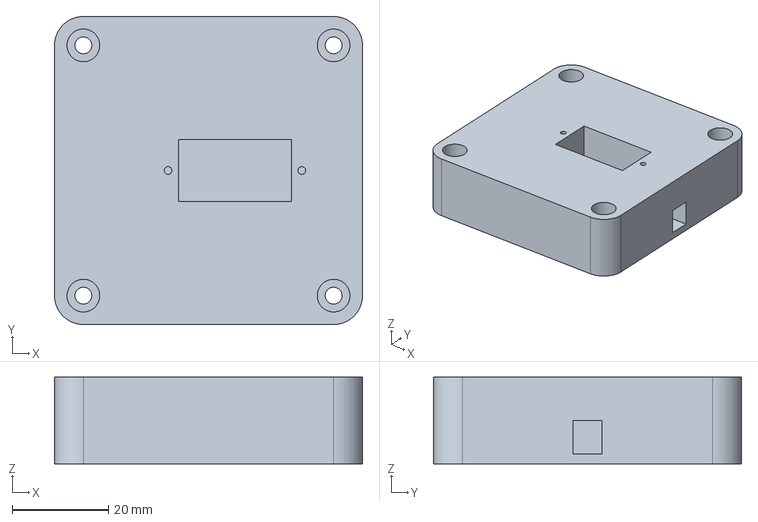
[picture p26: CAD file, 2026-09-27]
cad/flysonar/step/base.step
64.0 x 64.0 x 18.0 mm

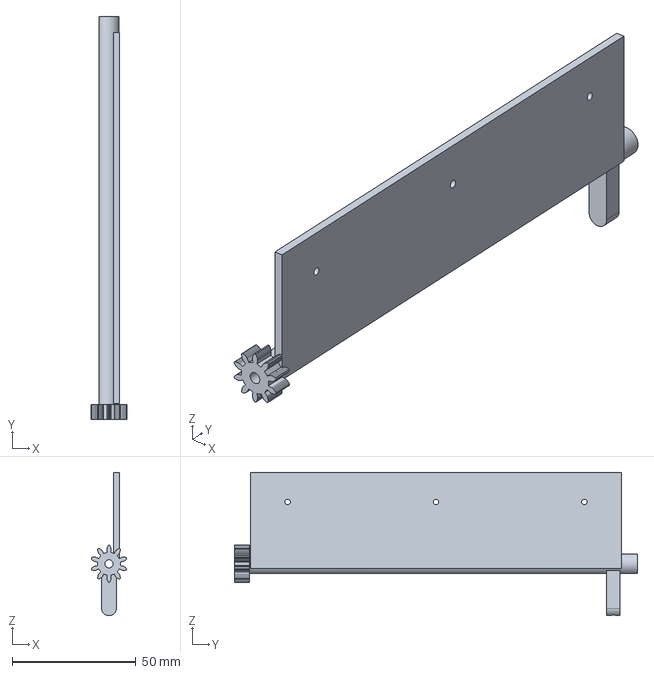
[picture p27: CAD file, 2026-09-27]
cad/flyclap/step/hinge_left.step
14.4 x 163.0 x 58.0 mm

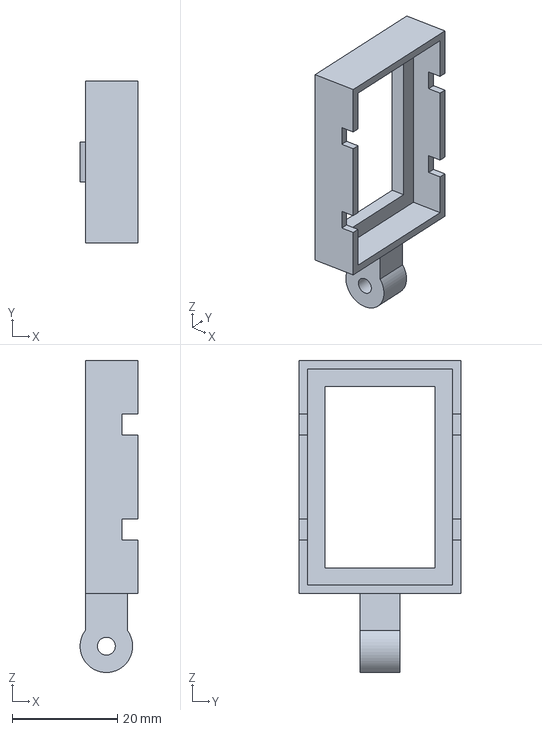
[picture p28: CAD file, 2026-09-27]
cad/flysonar/step/camera_cradle.step
11.0 x 30.8 x 59.3 mm

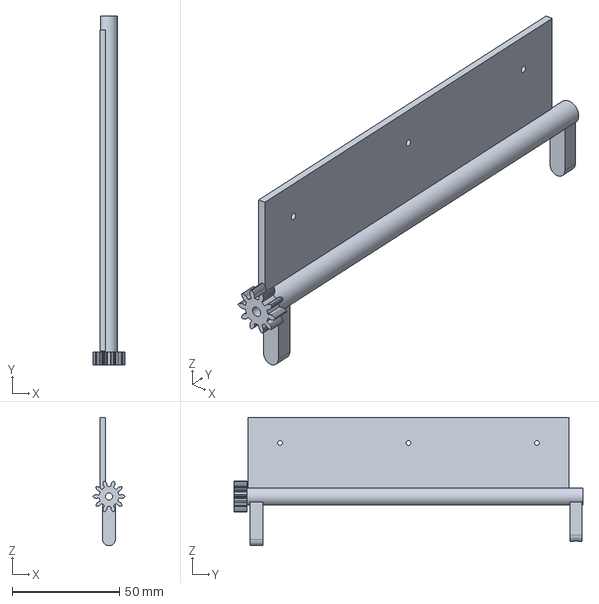
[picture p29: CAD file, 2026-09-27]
cad/flyclap/step/hinge_right.step
15.0 x 163.0 x 60.0 mm

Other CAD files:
cad/flysonar/step/camera_post.step
cad/flyclap/step/electronics_lid.step
cad/flysonar/step/yoke.step
cad/flysonar/step/head_sonar.step
cad/flyclap/step/bait_cup.step
cad/flyclap/step/latch_bolt.step
cad/flyclap/step/shell_right.step
cad/flyclap/stl/bait_cup.stl
cad/flyclap/stl/electronics_box.stl
cad/flyclap/stl/electronics_lid.stl
cad/flyclap/stl/hinge_left.stl
cad/flyclap/stl/hinge_right.stl
cad/flyclap/stl/latch_bolt.stl
cad/flyclap/stl/latch_mount.stl
cad/flyclap/stl/lid_mesh.stl
cad/flyclap/stl/shell_left.stl
cad/flyclap/stl/shell_right.stl
cad/flysonar/stl/base.stl
cad/flysonar/stl/camera_cradle.stl
cad/flysonar/stl/camera_post.stl
cad/flysonar/stl/electronics_box.stl
cad/flysonar/stl/electronics_lid.stl
cad/flysonar/stl/head_nozzle.stl
cad/flysonar/stl/head_sonar.stl
cad/flysonar/stl/yoke.stl

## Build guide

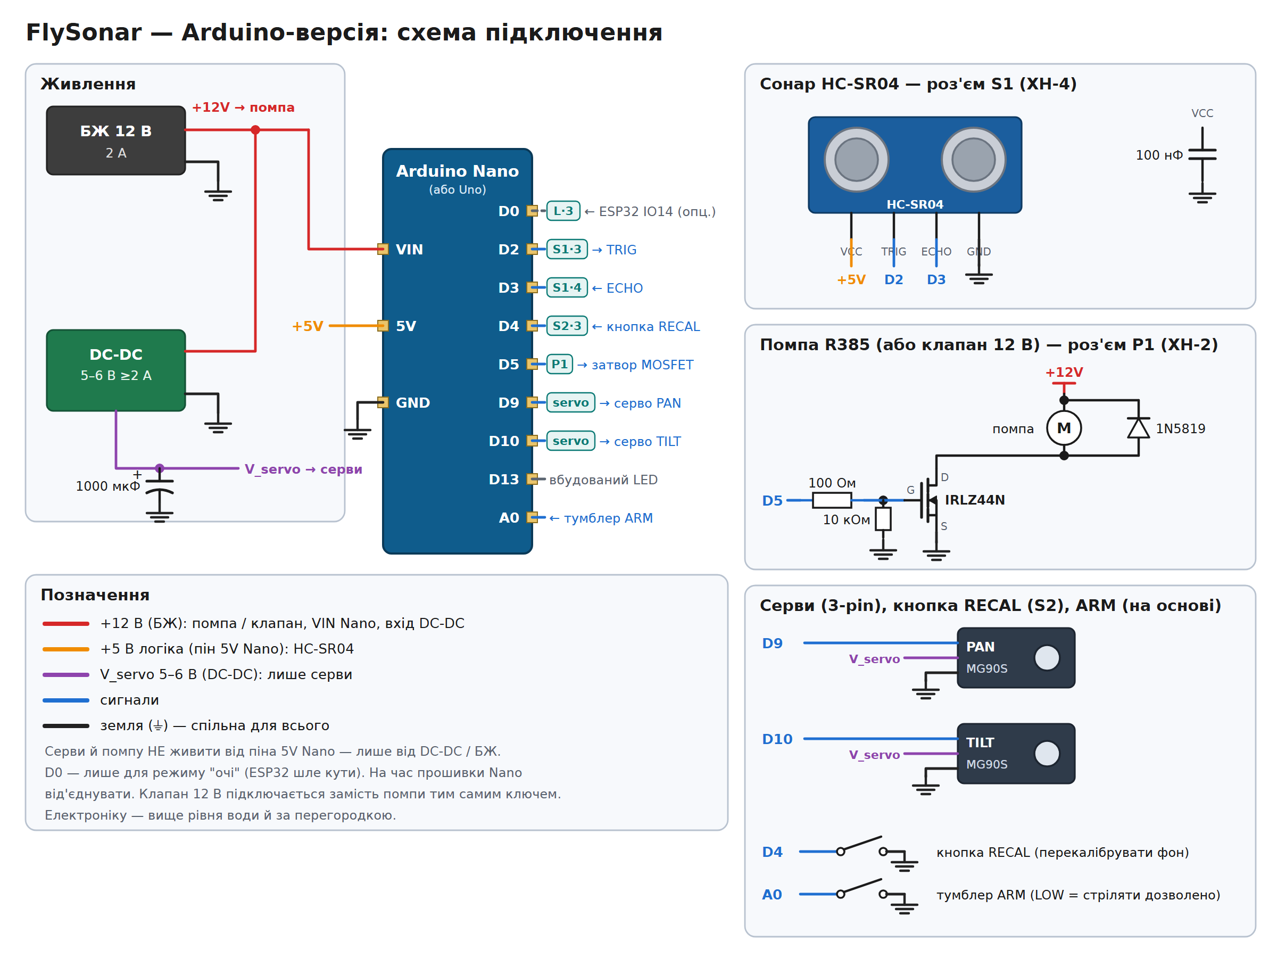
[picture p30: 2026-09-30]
schematics/png/flysonar-arduino-wiring.png

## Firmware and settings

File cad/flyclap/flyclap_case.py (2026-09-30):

#!/usr/bin/env python3
"""
FlyClap — корпус і механіка для 3D-друку (параметрична модель CadQuery).

Запуск з кореня репозиторію:
    pip install cadquery
    python3 cad/flyclap/flyclap_case.py

Результат:
    cad/flyclap/step/*.step        — кожна деталь окремо (відкривається у FreeCAD: File → Open)
    cad/flyclap/stl/*.stl          — для слайсера
    cad/flyclap/flyclap_assembly.step — складання (пластини відкриті, "взведено")
Скрипт також перевіряє, що деталі не перетинаються (відкрито й закрито)
і що кожна влазить на стіл 220×220×250 мм.

Система координат складання: X — ліво/право (0 — центральний шов),
Y — спереду назад (0 — передня площина), Z — вгору (0 — низ корпусу).
"""
import math
import os
import sys

import cadquery as cq

HERE = os.path.dirname(os.path.abspath(__file__))
sys.path.insert(0, os.path.dirname(HERE))
import cadlib  # noqa: E402  (спільна коробка основи з вікнами під роз'єми JST-XH)

# ============================ ПАРАМЕТРИ ============================
# Корпус
W, D, H = 200.0, 170.0, 200.0   # зовнішні розміри
T = 3.0                          # стінки
TF = 3.0                         # дно
BED = (220.0, 220.0, 250.0)      # стіл принтера для перевірки

# Пластини (оргскло, НЕ друкуються)
PLATE = 150.0                    # 150×150 мм
PLATE_T = 2.0
PLATE_Y0 = 10.0                  # пластина займає Y 10..160
OPEN_DEG = 35.0                  # кут розкриття кожної пластини від вертикалі

# Петлі: дві осі (пруток / шпилька Ø3) на відстані 2·AX_X, синхронізовані шестернями
AX_X = 6.25
AX_Z = 35.0
ROD_D = 3.0
BORE = 3.3                       # отвір у петлі (обертається на прутку)
ROD_HOLE = 3.2                   # отвір у стінці (пруток сидить щільно)
TUBE_R = 4.0
GEAR_M, GEAR_Z = 1.25, 10        # модуль і зуби: ділильний радіус = AX_X
GEAR_Y = (3.5, 9.5)
TAB_T = 2.5                      # вусо, до якого клеїться / кріпиться пластина
TAB_TOP = 72.0

# ІЧ-завіса
IR_Z = AX_Z + 90.0               # висота променів
IR_X = (13.0, 40.0)              # ± від центру
LED_BORE, LED_BOSS_R, LED_BOSS_L = 5.2, 4.6, 12.0     # TSAL6200, 5 мм
PT_BORE, PT_BOSS_R, PT_BOSS_L = 3.2, 3.6, 15.0        # TEFT4300, 3 мм

# Серво MG996R (звірте свій екземпляр!)
SERVO_L, SERVO_W, SERVO_H = 40.7, 19.7, 42.9
SERVO_SHAFT_FROM_END = 10.0
SERVO_HOLES_DX, SERVO_HOLES_DZ = 49.5, 10.0
SERVO_SHAFT = (22.0, 18.0)       # (x, z) осі серви на передній стінці
SERVO_TOP_INSIDE = 9.0           # наскільки верх серви заходить усередину

# Засувка й соленоїд JF-0530B (звірте свій екземпляр!)
LATCH_Y, LATCH_Z = 85.0, 165.0
BOLT = 6.0                       # переріз засувки 6×6
BOLT_TIP_X = -85.0               # кінчик засувки у висунутому стані
SOL_L, SOL_W, SOL_H = 30.0, 16.0, 14.0

# Стяжні болти половинок
SEAM_W = 9.0                     # ширина рамки шва (пластина починається з Y=10)
SEAM_GAP = (12.0, 58.0)          # проріз у рамці для шестерень / хвостовиків

CLR = 0.3                        # типовий зазор FDM

# Роз'єми основи FlyClap (docs/modules.md): вікна в зовнішній стінці блока електроніки,
# від переду корпусу до заду — так само, як розташовані модулі.
BASE_PORTS = [
    ("E: випромінювачі завіси (XH-3)", "XH3"),
    ("servo: взведення (3-pin)", "servo"),
    ("P1: соленоїд (XH-2)", "XH2"),
    ("S1: кінцевик (XH-4)", "XH4"),
    ("B: приймачі завіси (XH-6)", "XH6"),
]


# ============================ ПРИМІТИВИ ============================
def B(x0, x1, y0, y1, z0, z1):
    x0, x1 = min(x0, x1), max(x0, x1)
    return cq.Workplane("XY").box(x1 - x0, y1 - y0, z1 - z0, centered=False).translate((x0, y0, z0))


def cylY(x, z, r, y0, y1):
    return cq.Workplane("XZ").center(x, z).circle(r).extrude(-(y1 - y0)).translate((0, y0, 0))


def cylX(y, z, r, x0, x1):
    x0, x1 = min(x0, x1), max(x0, x1)
    return cq.Workplane("YZ").center(y, z).circle(r).extrude(x1 - x0).translate((x0, 0, 0))


def cylZ(x, y, r, z0, z1):
    return cq.Workplane("XY").center(x, y).circle(r).extrude(z1 - z0).translate((0, 0, z0))


def gear_profile(cx, cz, m, z, phase_deg, backlash=0.25, addendum=1.0, n=10):
    """Евольвентний профіль зубчастого колеса в площині XZ (точки (x, z)).
    Бічний зазор 0.25 мм — під FDM (±0.1–0.2 мм)."""
    alpha = math.radians(20)
    rp = m * z / 2
    rb = rp * math.cos(alpha)
    ra = rp + addendum * m
    rf = rp - 1.25 * m
    inv = lambda a: math.tan(a) - a
    s_p = math.pi * m / 2 - backlash
    psi_p = s_p / 2 / rp

    def half(r):
        if r <= rb:
            return psi_p + inv(alpha)
        return psi_p + inv(alpha) - inv(math.acos(rb / r))

    rs = [rb + (ra - rb) * i / n for i in range(n + 1)]
    pts = []
    for k in range(z):
        c = math.radians(phase_deg) + 2 * math.pi * k / z
        # западина → лівий бік зуба (від кореня до вершини) → вершина → правий бік
        flank_up = [(c - half(r), r) for r in rs]
        pts.append((c - half(rb), rf))
        pts += flank_up
        pts += [(c + half(r), r) for r in reversed(rs)]
        pts.append((c + half(rb), rf))
    return [(cx + r * math.cos(a), cz + r * math.sin(a)) for a, r in pts]


def gear(cx, cz, y0, y1, phase_deg):
    pts = gear_profile(cx, cz, GEAR_M, GEAR_Z, phase_deg)
    return cq.Workplane("XZ").polyline(pts).close().extrude(-(y1 - y0)).translate((0, y0, 0))


def mirrorX(wp):
    return wp.mirror("YZ")


# ============================ КОРПУС ============================
def shell(side):
    """Половина корпусу: side = +1 права, -1 ліва."""
    s = side
    X = lambda a: s * a
    body = B(0, X(W / 2), 0, D, 0, H)
    body = body.cut(B(X(-1), X(W / 2 - T), T, D - T, TF, H + 1))          # порожнина, шов відкритий

    # рамка шва (болти М3 стягують половинки)
    frame = (B(0, X(T), 0, SEAM_W, 0, SEAM_GAP[0])
             .union(B(0, X(T), 0, SEAM_W, SEAM_GAP[1], H))
             .union(B(0, X(T), D - SEAM_W, D, 0, SEAM_GAP[0]))
             .union(B(0, X(T), D - SEAM_W, D, SEAM_GAP[1], H))
             .union(B(0, X(T), 0, 30, 0, 11))
             .union(B(0, X(T), D - 30, D, 0, 11)))
    body = body.union(frame)
    for y, z in ((6, 6), (6, 80), (6, 140), (6, 190), (D - 6, 6), (D - 6, 80), (D - 6, 140), (D - 6, 190),
                 (22, 7), (D - 22, 7)):
        body = body.cut(cylX(y, z, 1.65, -5, 5))

    # стійки під гвинти кришки (в зовнішніх кутах)
    for y0 in (T, D - T - 8):
        post = B(X(W / 2 - T - 8), X(W / 2 - T), y0, y0 + 8, TF, H)
        body = body.union(post)
        body = body.cut(cylZ(X(W / 2 - T - 4), y0 + 4, 1.3, H - 16, H + 1))

    # отвори під осі петель (пруток Ø3 крізь передню і задню стінки)
    body = body.cut(cylY(X(AX_X), AX_Z, ROD_HOLE / 2, -1, D + 1))

    # ІЧ-тунелі: світлодіоди спереду, фототранзистори ззаду (деталь — на зовнішньому кінці)
    for x in IR_X:
        body = body.union(cylY(X(x), IR_Z, LED_BOSS_R, -LED_BOSS_L, T))
        body = body.cut(cylY(X(x), IR_Z, LED_BORE / 2, -LED_BOSS_L - 1, T + 1))
        body = body.union(cylY(X(x), IR_Z, PT_BOSS_R, D - T, D + PT_BOSS_L))
        body = body.cut(cylY(X(x), IR_Z, PT_BORE / 2, D - T - 1, D + PT_BOSS_L + 1))

    # стійки для гумки (закриває пластини)
    post_y = 163.0 if s > 0 else 157.0
    body = body.union(cylZ(X(45), post_y, 3, TF, 15)).union(cylZ(X(45), post_y, 4.5, 13, 15))

    if s > 0:
        # вікно під MG996R у передній стінці (корпус серви зовні, вал усередину)
        sx, sz = SERVO_SHAFT
        x0 = sx - SERVO_SHAFT_FROM_END
        body = body.cut(B(x0 - CLR, x0 + SERVO_L + CLR, -1, T + 1, sz - SERVO_W / 2 - CLR, sz + SERVO_W / 2 + CLR))
        cx = x0 + SERVO_L / 2
        for dx in (-SERVO_HOLES_DX / 2, SERVO_HOLES_DX / 2):
            for dz in (-SERVO_HOLES_DZ / 2, SERVO_HOLES_DZ / 2):
                body = body.cut(cylY(cx + dx, sz + dz, 1.5, -1, T + 1))
        # отвори під кріплення блока електроніки
        for y in (60, 110):
            body = body.cut(cylX(y, 100, 1.65, W / 2 - T - 1, W / 2 + 1))
    else:
        # вікно засувки + пази кріплення соленоїда (регулювання ±3 мм по висоті)
        body = body.cut(B(-W / 2 - 1, -W / 2 + T + 1, LATCH_Y - 7, LATCH_Y + 7, LATCH_Z - 7, LATCH_Z + 7))
        for dy in (-17, 17):
            for dz in (-15, 15):
                y, z = LATCH_Y + dy, LATCH_Z + dz
                body = body.cut(B(-W / 2 - 1, -W / 2 + T + 1, y - 1.7, y + 1.7, z - 3, z + 3))
                body = body.cut(cylX(y, z - 3, 1.7, -W / 2 - 1, -W / 2 + T + 1))
                body = body.cut(cylX(y, z + 3, 1.7, -W / 2 - 1, -W / 2 + T + 1))
    return body


def lid():
    """Кришка-сітка: вічко 8 мм, перемички 2 мм."""
    t = 2.4
    plate = B(-W / 2, W / 2, 0, D, H, H + t)
    nx, ny, pitch = 17, 14, 10.0
    holes = (cq.Workplane("XY").workplane(offset=H - 1)
             .center(0, D / 2).rarray(pitch, pitch, nx, ny).rect(8, 8).extrude(t + 2))
    plate = plate.cut(holes)
    for x in (-(W / 2 - T - 4), W / 2 - T - 4):
        for y in (T + 4, D - T - 4):
            plate = plate.cut(cylZ(x, y, 1.7, H - 1, H + t + 1))
    return plate


# ============================ ПЕТЛІ ============================
def hinge(side):
    """Петля пластини: трубка на прутку + шестерня синхронізації + вусо під пластину
    + хвостовик(и) під гумку / серво. Модель у ЗАКРИТОМУ стані (пластини вертикально)."""
    s = side
    # будуємо праву і дзеркалимо для лівої; фаза шестерні лівої — на півзуба
    ax, az = AX_X, AX_Z
    tube = cylY(ax, az, TUBE_R, GEAR_Y[0], D - T - 0.5)
    g = gear(ax, az, GEAR_Y[0], GEAR_Y[1], 0.0 if s > 0 else 18.0)
    tab = B(PLATE_T, PLATE_T + TAB_T, PLATE_Y0, PLATE_Y0 + PLATE, az - 2, TAB_TOP)
    part = tube.union(g).union(tab)
    # хвостовик під гумку (ззаду); лівий і правий — у різних площинах Y, щоб не зачепились
    ty = (160.5, 166.0) if s > 0 else (154.0, 159.5)
    tail = B(ax - 3, ax + 3, ty[0], ty[1], 17, az).union(cylY(ax, 17, 3, ty[0], ty[1]))
    part = part.union(tail).cut(cylZ(ax, (ty[0] + ty[1]) / 2, 1.2, 12, 22))  # отвір для гумки
    if s > 0:
        # хвостовик, який штовхає важіль серви при взводі (спереду)
        st = B(ax - 3, ax + 3, 11, 17, 15, az).union(cylY(ax, 15, 3, 11, 17))
        part = part.union(st)
    part = part.cut(cylY(ax, az, BORE / 2, -1, D + 1))
    for y in (25, 85, 145):                                               # М2 для пластини
        part = part.cut(cylX(y, 60, 1.1, -1, 10))
    if s < 0:
        part = mirrorX(part)
    return part


def plate(side):
    p = B(0, PLATE_T, PLATE_Y0, PLATE_Y0 + PLATE, AX_Z, AX_Z + PLATE)
    return p if side > 0 else mirrorX(p)


def rod(side):
    return cylY(side * AX_X, AX_Z, ROD_D / 2, -2, D + 2)


def rotate_open(wp, side, deg):
    """Повернути праву (+deg) / ліву (−deg) рухому частину навколо її осі."""
    a = (side * AX_X, 0, AX_Z)
    return wp.rotate(a, (a[0], 1, a[2]), side * deg)


# ============================ ЗАСУВКА ============================
def latch_mount():
    """Кріплення соленоїда зовні лівої стінки: пластина з 4 отворами, напрямна
    засувки 6×6 і люлька під соленоїд (кріпиться стяжками)."""
    x_wall = -W / 2
    y, z = LATCH_Y, LATCH_Z
    base = B(x_wall - 3, x_wall, y - 22, y + 22, z - 20, z + 20)
    for dy in (-17, 17):
        for dz in (-15, 15):
            base = base.cut(cylX(y + dy, z + dz, 1.7, x_wall - 5, x_wall + 1))
    guide = B(x_wall - 18, x_wall - 3, y - 7, y + 7, z - 7, z + 7)
    part = base.union(guide)
    # люлька: дно + дві стінки
    xs0, xs1 = x_wall - 20 - SOL_L - 2, x_wall - 18
    zb = z - SOL_H / 2
    part = part.union(B(xs0, xs1, y - SOL_W / 2 - 2, y + SOL_W / 2 + 2, zb - 2.5, zb))
    for sg in (-1, 1):
        yy = y + sg * (SOL_W / 2 + 1)
        part = part.union(B(xs0, xs1, yy - 1, yy + 1, zb - 2.5, z + SOL_H / 2 - 3))
    # перемичка люлька ↔ напрямна (з перекриттям, щоб деталь була одним тілом)
    part = part.union(B(x_wall - 22, x_wall - 10, y - 7, y + 7, zb - 2.5, zb + 1))
    # канал засувки і прорізи під стяжки
    part = part.cut(B(x_wall - 30, x_wall + 1, y - BOLT / 2 - CLR, y + BOLT / 2 + CLR, z - BOLT / 2 - CLR, z + BOLT / 2 + CLR))
    for xx in (xs0 + 8, xs1 - 8):
        part = part.cut(B(xx - 2, xx + 2, y - SOL_W / 2 - 3, y + SOL_W / 2 + 3, zb - 3, zb + 0.01))
    return part


def latch_bolt(extended=True):
    """Засувка 6×6 зі скосом зверху: пластина при взводі відсуває її, а закритися не може."""
    tip = BOLT_TIP_X if extended else BOLT_TIP_X - 5
    L = 38.0
    y, z = LATCH_Y, LATCH_Z
    bolt = B(tip - L, tip, y - BOLT / 2, y + BOLT / 2, z - BOLT / 2, z + BOLT / 2)
    wedge = (cq.Workplane("XZ").polyline([(tip - 5, z + BOLT / 2), (tip, z + BOLT / 2), (tip, z - BOLT / 2 + 1.5)])
             .close().extrude(-(BOLT + 2)).translate((0, y - BOLT / 2 - 1, 0)))
    bolt = bolt.cut(wedge)
    bolt = bolt.cut(cylZ(tip - L + 4, y, 1.1, z - 5, z + 5))            # отвір для зв'язку з якорем
    return bolt


# ============================ ЕЛЕКТРОНІКА, ПРИМАНКА ============================
def elec_box():
    """Коробка основи під плату 5×7 см (Nano, MOSFET, компаратор) з вікнами під
    роз'єми модулів. Вухо з двома отворами кріпиться до правої стінки корпусу.
    Локальні координати: x — від стінки назовні."""
    return cadlib.base_box(BASE_PORTS, ear=True)


def elec_lid():
    return cadlib.base_lid()


def bait_cup():
    return cylZ(0, 0, 25, 0, 20).cut(cylZ(0, 0, 23.4, 1.6, 21))


# ============================ МУЛЯЖІ (не друкуються) ============================
def servo_dummy():
    sx, sz = SERVO_SHAFT
    x0 = sx - SERVO_SHAFT_FROM_END
    top_y = T + SERVO_TOP_INSIDE
    body = B(x0, x0 + SERVO_L, top_y - SERVO_H, top_y, sz - SERVO_W / 2, sz + SERVO_W / 2)
    fl = B(x0 - 7, x0 + SERVO_L + 7, -2.5, 0, sz - SERVO_W / 2, sz + SERVO_W / 2)
    return body.union(fl).union(cylY(sx, sz, 3, top_y, top_y + 4))


def solenoid_dummy():
    xs1 = -W / 2 - 20
    return B(xs1 - SOL_L, xs1, LATCH_Y - SOL_W / 2, LATCH_Y + SOL_W / 2,
             LATCH_Z - SOL_H / 2, LATCH_Z + SOL_H / 2)


# ============================ ЗБІРКА, ПЕРЕВІРКИ, ЕКСПОРТ ============================
PRINTED = {
    "shell_right": lambda: shell(+1),
    "shell_left": lambda: shell(-1),
    "lid_mesh": lid,
    "hinge_right": lambda: hinge(+1),
    "hinge_left": lambda: hinge(-1),
    "latch_mount": latch_mount,
    "latch_bolt": latch_bolt,
    "electronics_box": elec_box,
    "electronics_lid": elec_lid,
    "bait_cup": bait_cup,
}


def assembly_parts(parts, opened=True, deg=None):
    if deg is None:
        deg = OPEN_DEG if opened else 0.0
    ebox_place = lambda wp: wp.translate((W / 2, 35, 48))
    items = [
        ("shell_right", parts["shell_right"], (0.93, 0.93, 0.95)),
        ("shell_left", parts["shell_left"], (0.93, 0.93, 0.95)),
        ("lid_mesh", parts["lid_mesh"], (0.55, 0.58, 0.62)),
        ("hinge_right", rotate_open(parts["hinge_right"], +1, deg), (0.95, 0.55, 0.15)),
        ("hinge_left", rotate_open(parts["hinge_left"], -1, deg), (0.95, 0.55, 0.15)),
        ("plate_right", rotate_open(plate(+1), +1, deg), (0.6, 0.8, 1.0)),
        ("plate_left", rotate_open(plate(-1), -1, deg), (0.6, 0.8, 1.0)),
        ("rod_right", rod(+1), (0.4, 0.4, 0.4)),
        ("rod_left", rod(-1), (0.4, 0.4, 0.4)),
        ("latch_mount", parts["latch_mount"], (0.2, 0.45, 0.8)),
        ("latch_bolt", latch_bolt(extended=True), (0.85, 0.2, 0.2)),
        ("electronics_box", ebox_place(parts["electronics_box"]), (0.25, 0.28, 0.33)),
        ("electronics_lid", ebox_place(parts["electronics_lid"].translate((0, 0, 40))), (0.25, 0.28, 0.33)),
        ("base_pcb", ebox_place(cadlib.pcb_dummy()), (0.1, 0.45, 0.25)),
        ("base_plugs", ebox_place(cadlib.plug_dummies(BASE_PORTS)), (0.92, 0.9, 0.82)),
        ("bait_cup", parts["bait_cup"].translate((0, 85, TF)), (0.95, 0.75, 0.35)),
        ("servo_MG996R", servo_dummy(), (0.18, 0.2, 0.25)),
        ("solenoid_JF0530B", solenoid_dummy(), (0.45, 0.45, 0.45)),
    ]
    return items


def overlap(a, b):
    try:
        v = a.val().intersect(b.val()).Volume()
    except Exception:
        v = float("nan")
    return v


def checks(parts):
    ok = True
    print("\n== Розміри деталей (стіл %gx%gx%g) ==" % BED)
    for name, wp in parts.items():
        bb = wp.val().BoundingBox()
        dims = sorted([bb.xlen, bb.ylen])
        fits = dims[0] <= BED[0] and dims[1] <= BED[1] and bb.zlen <= BED[2]
        # деталі, що друкуються лежачи, влазять і так
        if not fits:
            d3 = sorted([bb.xlen, bb.ylen, bb.zlen])
            fits = d3[0] <= BED[2] and d3[1] <= BED[0] and d3[2] <= BED[1]
        one = len(wp.val().Solids()) == 1 and wp.val().isValid()   # друкується одним шматком
        ok &= fits and one
        print(f"  {name:18s} {bb.xlen:6.1f} × {bb.ylen:6.1f} × {bb.zlen:6.1f} мм   {'OK' if fits else 'НЕ ВЛАЗИТЬ'}"
              f"{'' if one else '   НЕ ОДНЕ ТІЛО!'}")

    pairs = [("hinge_right", "shell_right"), ("hinge_left", "shell_left"), ("hinge_right", "hinge_left"),
             ("hinge_right", "shell_left"), ("hinge_left", "shell_right"),
             ("plate_right", "shell_right"), ("plate_left", "shell_left"), ("plate_right", "plate_left"),
             ("plate_right", "hinge_left"), ("plate_left", "hinge_right"),
             ("bait_cup", "hinge_right"), ("bait_cup", "hinge_left"), ("bait_cup", "shell_right"),
             ("latch_bolt", "plate_left"), ("latch_bolt", "hinge_left"),
             ("servo_MG996R", "shell_right"), ("servo_MG996R", "hinge_right"),
             ("lid_mesh", "shell_right"), ("lid_mesh", "shell_left"),
             ("electronics_box", "shell_right"), ("latch_mount", "shell_left"),
             ("base_pcb", "electronics_box"), ("base_plugs", "electronics_box"), ("base_pcb", "electronics_lid"),
             ("rod_right", "hinge_right"), ("rod_left", "hinge_left")]
    for opened in (True, False):
        items = {n: w for n, w, _ in assembly_parts(parts, opened)}
        print(f"\n== Перетини деталей: пластини {'ВІДКРИТІ (взведено)' if opened else 'ЗАКРИТІ'} ==")
        for a, b in pairs:
            if not opened and a == "latch_bolt":
                continue                                   # у закритому стані засувка не заважає пластині — вона вище
            v = overlap(items[a], items[b])
            good = v < 0.5                                 # мм³: дотик/похибка тесселяції
            ok &= good
            print(f"  {a:16s} ∩ {b:16s} = {v:8.2f} мм³  {'OK' if good else 'ПЕРЕТИН!'}")
    # рух: шестерні, хвостовики й пластини на проміжних кутах
    print("\n== Хід пластин 0…%g° (крок 5°): рухомі деталі ∩ корпус / одна одну ==" % OPEN_DEG)
    moving = [("hinge_right", "hinge_left"), ("hinge_right", "shell_right"), ("hinge_left", "shell_left"),
              ("hinge_right", "shell_left"), ("hinge_left", "shell_right"),
              ("plate_right", "shell_right"), ("plate_left", "shell_left"), ("plate_right", "plate_left"),
              ("hinge_right", "bait_cup"), ("hinge_left", "bait_cup")]
    worst = 0.0
    for deg in range(0, int(OPEN_DEG) + 1, 5):
        items = {n: w for n, w, _ in assembly_parts(parts, deg=float(deg))}
        for a, b in moving:
            v = overlap(items[a], items[b])
            worst = max(worst, v)
            if v >= 0.5:
                ok = False
                print(f"  {deg:2d}°: {a} ∩ {b} = {v:.2f} мм³  ПЕРЕТИН!")
    print(f"  найбільший перетин на всьому ході: {worst:.2f} мм³  {'OK' if worst < 0.5 else 'ПЕРЕТИН!'}")
    # засувка справді тримає пластину: у відкритому стані вона нависає над верхнім торцем
    items = {n: w for n, w, _ in assembly_parts(parts, True)}
    pl = items["plate_left"].val().BoundingBox()
    bolt = items["latch_bolt"].val().BoundingBox()
    holds = bolt.xmax > pl.xmin + 2 and bolt.zmin >= pl.zmax - 0.01
    print(f"\n== Засувка над торцем лівої пластини: кінчик x={bolt.xmax:.1f}, край пластини x={pl.xmin:.1f}, "
          f"низ засувки z={bolt.zmin:.1f}, верх пластини z={pl.zmax:.1f}  {'OK' if holds else 'НЕ ТРИМАЄ'}")
    ok &= holds
    return ok


def export(parts):
    os.makedirs(os.path.join(HERE, "step"), exist_ok=True)
    os.makedirs(os.path.join(HERE, "stl"), exist_ok=True)
    for name, wp in parts.items():
        cq.exporters.export(wp, os.path.join(HERE, "step", name + ".step"))
        cq.exporters.export(wp, os.path.join(HERE, "stl", name + ".stl"), tolerance=0.05, angularTolerance=0.15)
    asm = cq.Assembly(name="FlyClap")
    for name, wp, rgb in assembly_parts(parts, True):
        asm.add(wp, name=name, color=cq.Color(*rgb))
    asm.save(os.path.join(HERE, "flyclap_assembly.step"))
    print("\nЕкспорт: step/, stl/, flyclap_assembly.step")
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

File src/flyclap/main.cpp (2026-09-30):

/*
 * FlyClap — автоматична "хлопавка" для мух (Arduino Uno / Nano).
 *
 * Муха перетинає ІЧ-завісу → переривання одразу відкриває соленоїд-засувку →
 * пружинні пластини схлопуються → серво знову взводить механізм.
 * Опис механіки й складання — docs/flyclap.md.
 *
 * Модулі:  основа + IrCurtain (тригер) + ClapLatch (виконавець)
 * Збірка:  pio run -e flyclap -t upload   (flyclap_tssp — завіса TSSP4038, flyclap_nano — Nano)
 *
 * Пінаут:
 *   D3      — (лише TSSP) несуча 38 кГц на ключ ІЧ-світлодіодів
 *   D4..D7  — промені завіси (цілий = LOW, перекритий = HIGH)
 *   D8      — кінцевик "взведено" (до GND)
 *   D9      — затвор MOSFET соленоїда (IRLZ44N)
 *   D10     — серво взведення (MG996R)
 *   D11     — бузер: пасивний; для TSSP — активний
 *   D13     — статус-LED
 *   A0      — тумблер ARM (до GND)
 */
#include <Arduino.h>
#include <FlyDefense.h>

// Завіса: 0 — фототранзистори + LM339, 1 — приймачі TSSP4038 (не бояться сонця)
#ifndef BEAM_SENSOR_TSSP
#define BEAM_SENSOR_TSSP 0
#endif

fly::Base base(A0, 13);  // тумблер ARM, статус-LED
fly::IrCurtain curtain(4, 5, 6, 7, BEAM_SENSOR_TSSP ? fly::IrCurtain::TSSP : fly::IrCurtain::COMPARATOR);
fly::ClapLatch clap(curtain, 9, 10, 8);  // соленоїд, серво, кінцевик

void setup() {
  base.buzzer(11, BEAM_SENSOR_TSSP);  // TSSP займає Timer2, тож бузер активний
  base.add(curtain);
  base.add(clap);
  base.begin();
}

void loop() { base.update(); }

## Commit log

2026-09-27 Apply firmware fixes and hardware optimizations for FlyClap and FlySonar
    FlyClap:
    - Attach the cocking servo only while moving, detach at rest (no jitter/noise/current)
    - Read the ISR fire timestamp atomically
    - Rename the kill counter to claps (it counts triggers, not confirmed flies)
    - Optional TSSP4038 modulated curtain (BEAM_SENSOR_TSSP): 38 kHz carrier on D3 via Timer2
    - Docs: full BOM, comparator hysteresis, solenoid bulk cap, Nano option
    FlySonar:
    - Wait for ECHO to drop before triggering (no-echo pulse is ~38 ms, every other ping was lost)
    - Reuse fresh sweep data for the wide-object check instead of re-moving servos
    - Compute aim angles in int and clamp before narrowing to uint8_t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
2026-09-27 Add consolidated shopping list for both devices
    Claude-Session: https://claude.ai/code/session_012AKxy4Jujess734qN5thMC
2026-09-27 FlySonar precision upgrade: centroid aiming, camera mode (FlyVision), valve shooter
    FlySonar (Arduino):
    - Servo control via writeMicroseconds with 0.1 deg resolution, settle time from move size
    - Fine centroid scan (+/-10 deg, 2 deg step, window re-centred on edge hits) after
    a coarse detection: aim error <=0.5 deg in simulation vs 2-7 deg on the 5 deg grid
    - Still-target check; STATIC_ONLY (default) fires only at a sitting fly
    - Fix big-object filter: the ~16 deg beam lights 3-4 grid cells even for a point
    target, so ">=2 of +/-2 neighbours" rejected real flies, and edge-first hits let
    hands through. Now measures the contiguous span in both directions
    - SHOOTER_VALVE: solenoid valve +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
2026-09-27 FlySonar: split into Arduino and ESP32 versions
    ESP32 version (firmware/flysonar_esp32, renamed from flyvision) now runs
    standalone on one ESP32-CAM / ESP32-S3-CAM: vision + pan/tilt servos +
    valve + ARM switch, no Arduino needed.
    - turret.h: shot-gating logic (ARM, servo settle, fresh request, burst,
    cooldown, big-object hold) shared semantics with the Arduino version,
    host-tested in tools/turret_test.cpp
    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
2026-09-27 Restructure shopping list into full kits per device
    FlyClap, FlySonar Arduino version and FlySonar ESP32 version each get a
    complete, self-contained list; optional accuracy upgrades and tools moved
    to their own sections.
    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
2026-09-27 Add wiring diagrams and device illustrations (SVG)
    docs/images, generated by tools/diagrams.py (stdlib only):
    - flyclap-wiring.svg: variant A (phototransistors + LM339, hysteresis,
    solenoid driver, servo, limit switch, buzzer, ARM)
    - flyclap-tssp.svg: variant B (TSSP4038 receivers, 38 kHz LED driver)
    - flysonar-arduino-wiring.svg: Nano, HC-SR04, pump/valve driver, servos
    - flysonar-esp32-wiring.svg: ESP32-CAM pins, AO3400 valve driver, servos,
    ARM on strapping pin, Freenove S3 pin map
    - flyclap-device / flysonar-arduino-device / flysonar-esp32-device:
    how each device looks, with labelled parts
    Embedded in the device docs and a gallery in the README.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
    [diagrams.py]
2026-09-27 Move pictures to a dedicated schematics/ folder, add PNG versions
    - docs/images -> schematics/ (SVG), plus schematics/png/ at 2x (2400 px
    wide) for phones and printing
    - schematics/README.md: index of all pictures with SVG/PNG links
    - tools/diagrams.py writes to schematics/ and exports PNG with --png
    (headless Chromium, path overridable via CHROME)
    - Links in README and device docs updated; all relative links verified
    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
2026-09-27 Add 3D-printable FlyClap enclosure (CadQuery model, STEP for FreeCAD, STL)
    cad/flyclap/flyclap_case.py — parametric model:
    - two 100 x 170 x 200 mm halves bolted along the centre seam (fits a
    220 x 220 bed), mesh lid with 8 mm openings
    - hinges on 3 mm rods with meshing gears (m 1.25, z 10) so both plates
    move together: one latch and one servo for both; closed plates meet
    exactly at the centre
    - IR tunnels in front/back walls (components at the outer end shield the
    beam), MG996R window, solenoid latch mount with slotted height
    adjustment and bevelled bolt, rubber-band posts, electronics box, bait cup
    - self-checks: bed fit, single valid solid per part, zero interference in
    open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
    [bait_cup.step, bait_cup.stl, electronics_box.step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]
2026-09-27 Add 3D-printable FlySonar pan-tilt turret for both versions
    cad/flysonar/flysonar_turret.py — parametric CadQuery model:
    - base with pocket for the PAN micro servo (MG90S / SG90 / ES08MD),
    platter + yoke with window for the TILT servo and an M3 pivot screw,
    hose clip; PAN and TILT axes intersect so aim does not shift
    - head_sonar (Arduino version): HC-SR04 mounted pins-up in open-top
    U-slots, 4 mm nozzle below; head_nozzle (ESP32 version): nozzle exactly
    on the tilt axis; camera_post + camera_cradle for ESP32-CAM
    - self-checks: bed fit, single valid solid per part, zero interference
    across tilt -35..45 deg and pan -90..90 deg for both heads, HC-SR04
    can be slid in from the top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
    [base.step, base.stl, camera_cradle.step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]
2026-09-27 Shopping list: add 3D-printing section for the FlyClap case and FlySonar turret
    - New section 6: filament estimate from model volumes (FlyClap case is
    near-solid 3 mm walls: 0.8-1 kg; turret + camera mount 0.1-0.2 kg) and
    the fastener lists for both printed designs
    - FlyClap mechanics, pan-tilt bracket and camera bracket rows now point to
    the printed alternative; overview table links the new section
    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
2026-09-30 refactor for arduino
